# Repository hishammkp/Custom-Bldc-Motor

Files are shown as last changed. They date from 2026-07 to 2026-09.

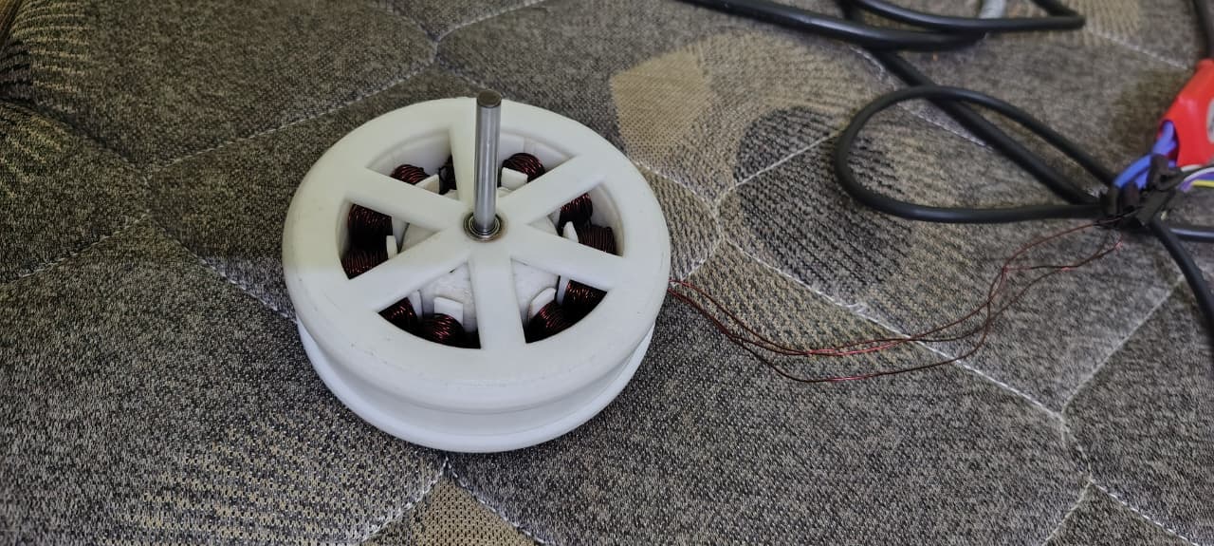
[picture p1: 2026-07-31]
Images/AssembledMotor.jpeg

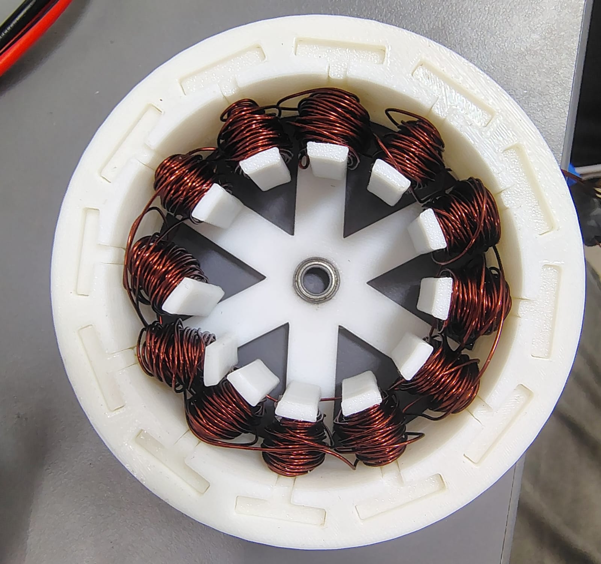
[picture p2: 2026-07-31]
Images/StatorWindings.jpeg

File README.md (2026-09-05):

# Custom BLDC Motor Design

A custom **12-slot, 8-pole Brushless DC (BLDC) motor** designed and developed as part of an electrical engineering coursework project. The project involved the complete engineering workflow, including motor design, CAD modeling, 3D printing, stator winding, assembly, simulation, and experimental validation.

## Overview

The objective of this project was to design and fabricate a functional BLDC motor from scratch rather than using a commercially available motor. The stator, rotor, and supporting components were modeled in Onshape, fabricated using 3D printing, assembled with hand-wound copper windings and permanent magnets, and evaluated through simulation and practical testing.

## Features

* Custom 12-slot, 8-pole inner-rotor BLDC motor
* CAD modeling using Onshape
* 3D-printed stator, rotor, and support components
* Hand-wound stator coils with Star (Y) connection
* Electromagnetic simulation and back-EMF analysis
* Prototype fabrication, assembly, and testing
* Iterative design improvements based on experimental observations

## Design Specifications

| Parameter | Value |
| --- | --- |
| Motor Type | Brushless DC (BLDC) |
| Topology | Inner Rotor |
| Slots | 12 |
| Poles | 8 |
| Winding Connection | Star (Y) |
| Wire Diameter | 0.5 mm Enamelled Copper |
| Winding Factor | 0.866 |

## Software Used

* Onshape
* Altair FluxMotor 2026
* Bambu Studio

## Challenges & Improvements

During fabrication and testing, manufacturing tolerances led to stator slot breakage, low rotor infill caused instability, and magnets detached at higher speeds. These issues were mitigated through stator modifications, improved magnet retention, and iterative design refinements, resulting in a more robust and reliable prototype.

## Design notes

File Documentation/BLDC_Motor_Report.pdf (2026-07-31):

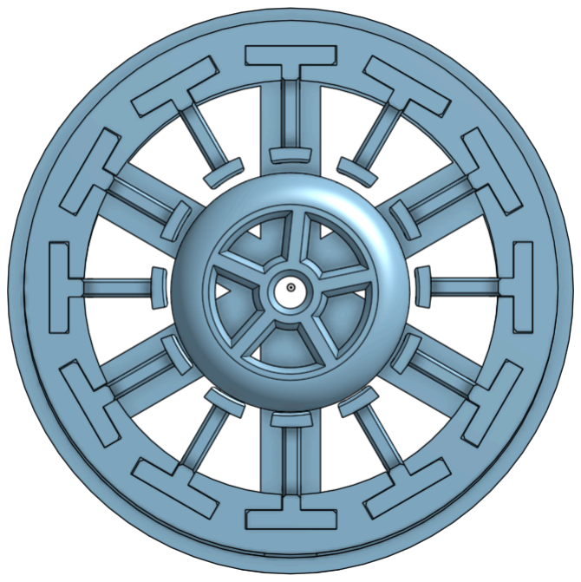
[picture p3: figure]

# BRUSHLESS DC MOTOR

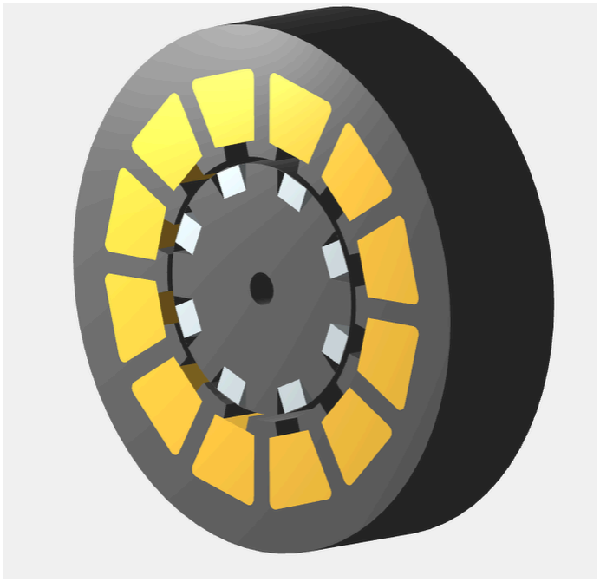
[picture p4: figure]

A Brushless DC (BLDC) motor operates through the interaction of a rotating magnetic field in the stator and permanent magnets in the rotor, generating torque based on the Lorentz Force. Unlike brushed motors, it uses electronic commutation, making it more efficient, reliable, and low maintenance.
DC supply is converted into a 3-phase supply using an ESC (Electronic Speed Controller)
The 3-phase supply is fed to the stator (Y-connected 3-phase windings), creating a rotating magnetic field (RMF)
The rotor contains strong permanent neodymium magnets, whose magnetic field aligns with the RMF, resulting in torque generation

# Understanding How a BLDC Motor Works

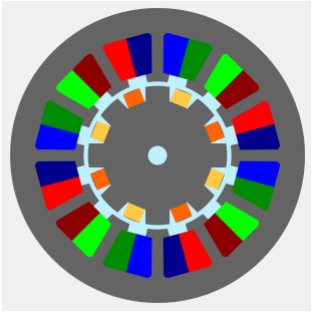
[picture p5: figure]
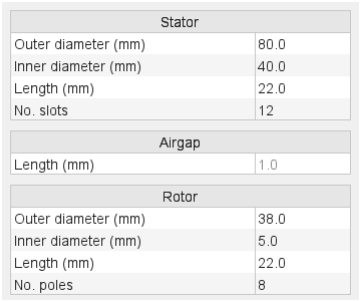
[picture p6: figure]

16 Slot 8pole Inner Rotor | Stator and Rotor Parameters

# Topology of motor

# Stator Winding

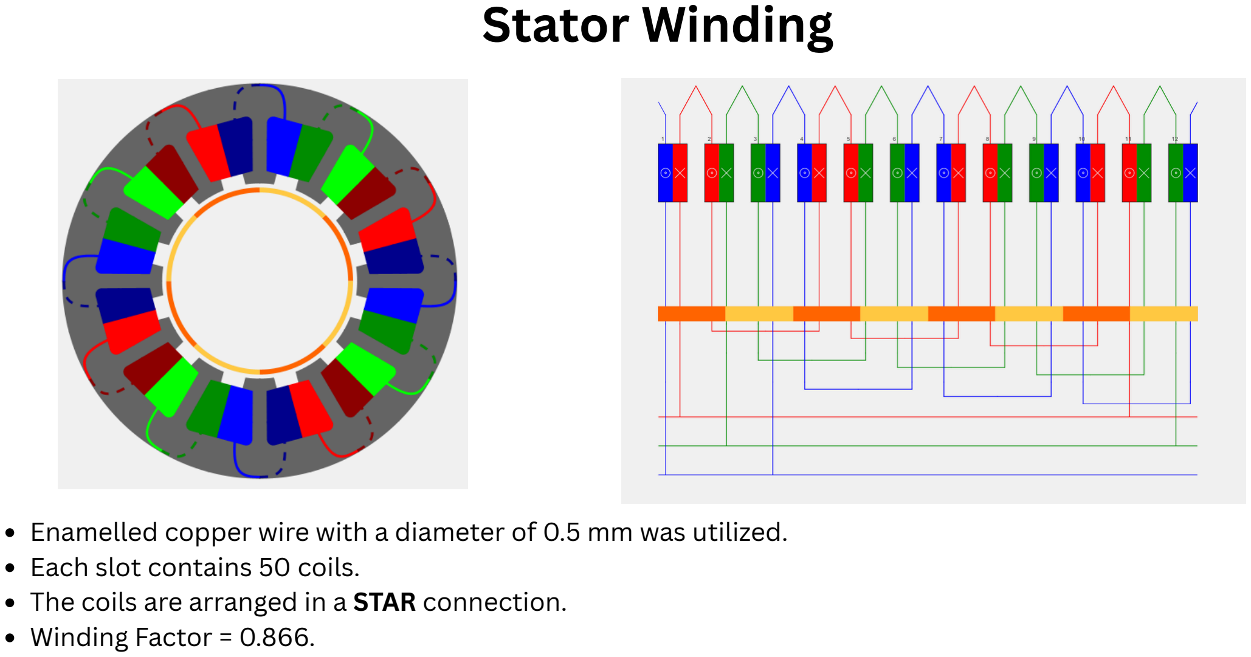
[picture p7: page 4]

Enamelled copper wire with a diameter of 0.5 mm was utilized. Each slot contains 50 coils.
The coils are arranged in a STAR connection.
Winding Factor = 0.866.

# CAD Design

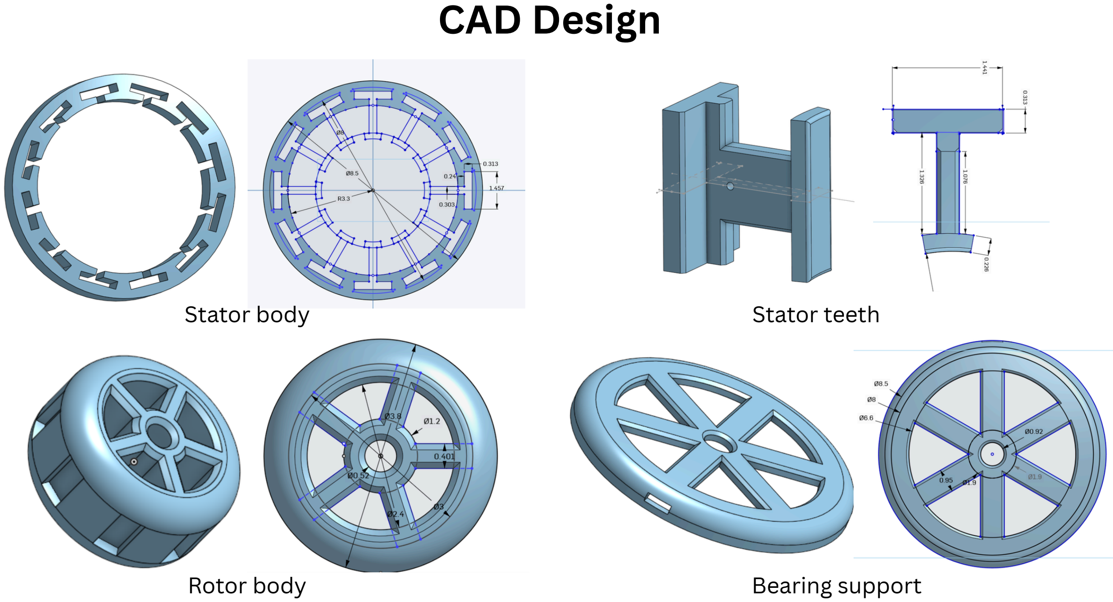
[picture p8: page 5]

Stator body | Stator teeth

Bearing support

Rotor body

# Assembly

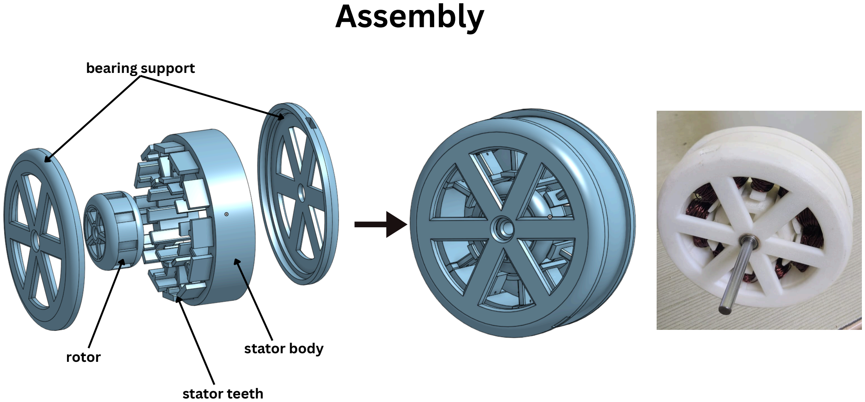
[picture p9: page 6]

bearing support

stator body

stator teeth

rotor

# Simulation

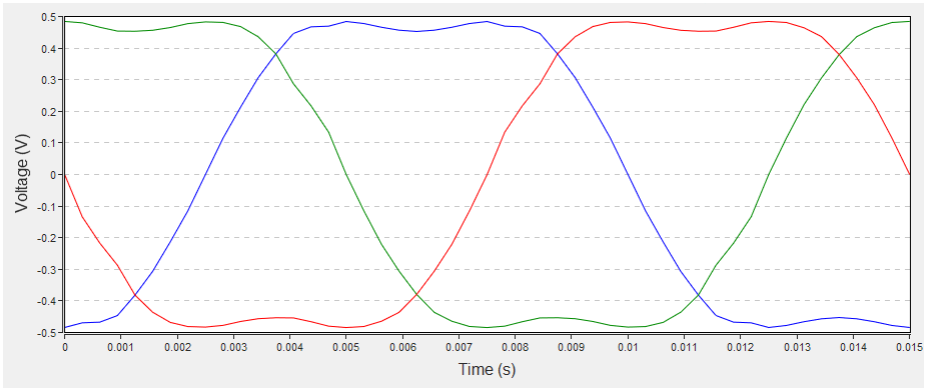
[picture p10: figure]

Phase voltage versus time - Open circuit Test speed = 1000RPM

BLDC motors have a characteristic trapezoidal back EMF waveform, which occurs because the stator winding interacts with rectangular permanent magnets on the rotor

Flat region (under North pole)
Sudden drop (at the edge of the magnet) Flat region (under South pole)
Sudden rise (at the edge of the magnet)

This results in a quasi-trapezoidal back EMF waveform, which is typical for BLDC motors.
The small ripples observed on the waveform are due to harmonics that combine (via Fourier series) to form the final trapezoidal shape.

# Back emf test

# Flux Density Due to Rotor Magnets

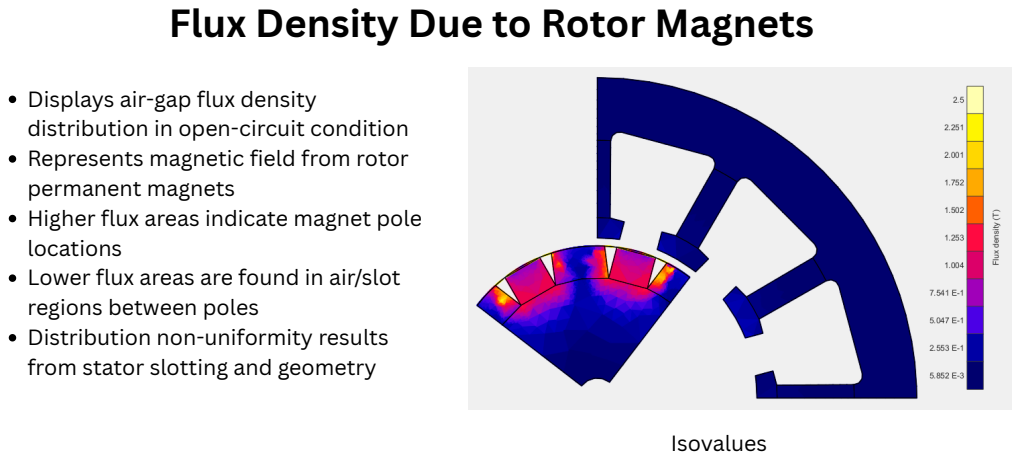
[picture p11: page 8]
Isovalues

Displays air-gap flux density
distribution in open-circuit condition
Represents magnetic field from rotor
permanent magnets
Higher flux areas indicate magnet pole
locations
Lower flux areas are found in air/slot
regions between poles
Distribution non-uniformity results
from stator slotting and geometry

Differences in CAD model and particle 3D model tolerances led to repeated breakage of stator slots
Low 3D fill (15%) resulted in a lighter rotor, which caused increased instability and wobbling
At high speeds, rotor magnets dislodged, resulting in damage to the stator Selection of appropriate vendor for components
SOLUTION
Sanded the stator's teeth to create additional space for the rotor and mitigate vibrations
Secured the magnets using superglue and added tape to minimize the risk of them coming loose

# Challenges faced and solutions implemented

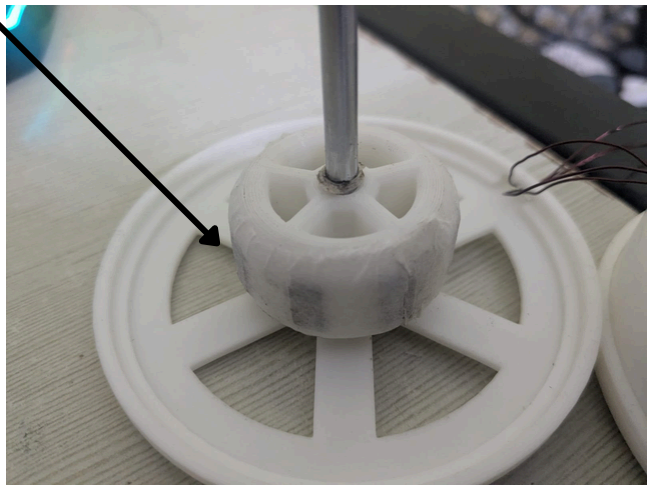
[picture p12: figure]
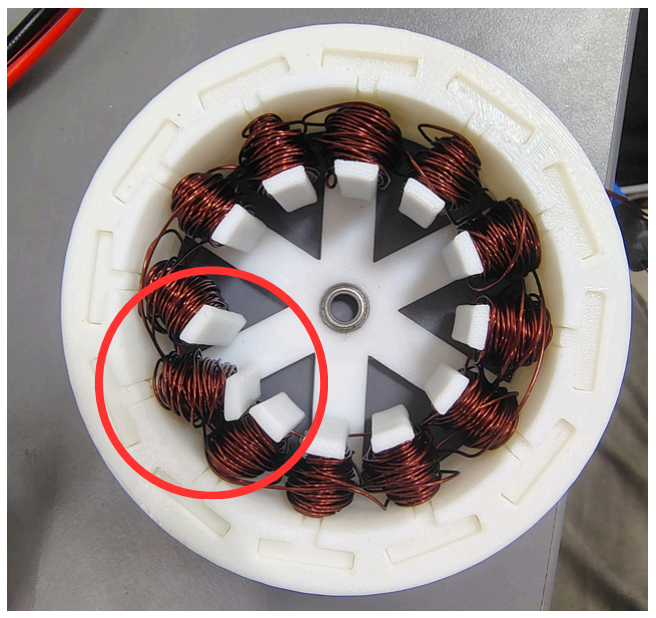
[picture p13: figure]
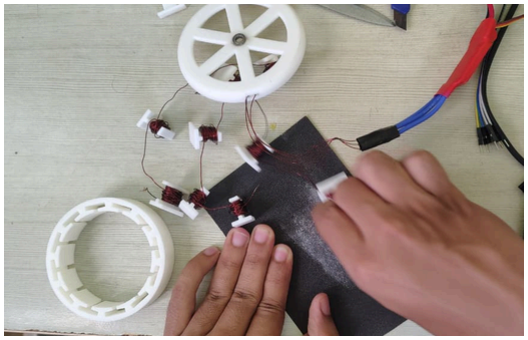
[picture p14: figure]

Onshape
Altair Flux Motor 2026
Bambu Studio

# Softwares used

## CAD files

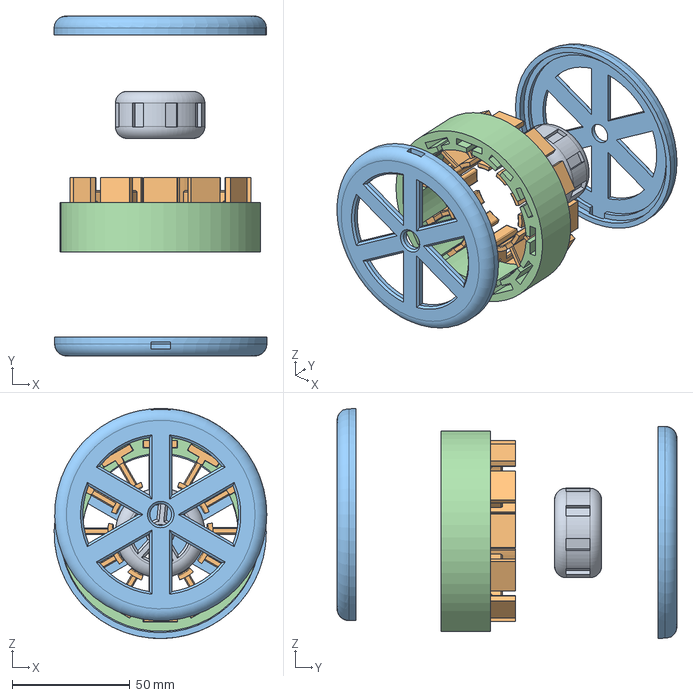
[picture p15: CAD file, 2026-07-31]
CAD/STEP/Assembly.step
90.2 x 144.2 x 97.6 mm

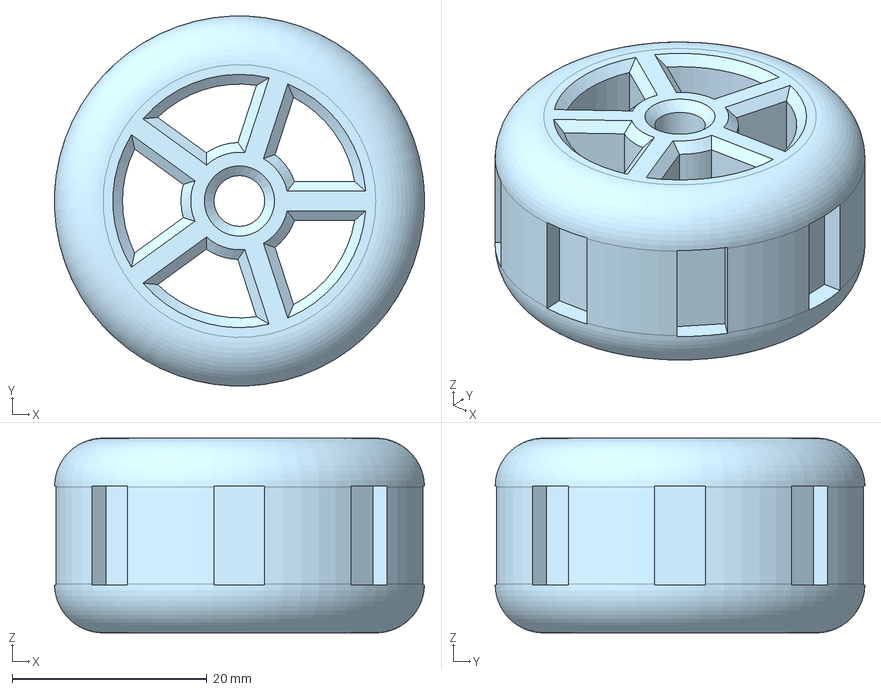
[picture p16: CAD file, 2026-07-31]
CAD/STEP/Rotor.step
38.0 x 38.0 x 20.0 mm

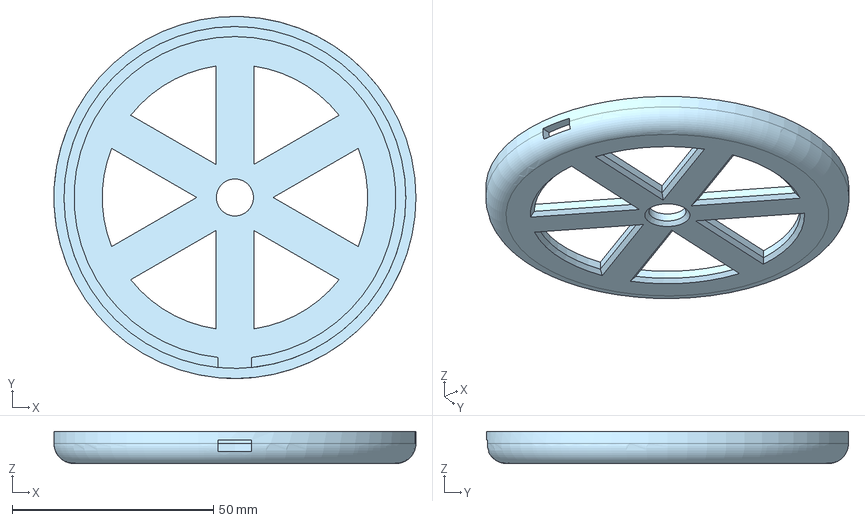
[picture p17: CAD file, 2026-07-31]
CAD/STEP/StatorFrontCover.step
90.0 x 90.0 x 8.00 mm

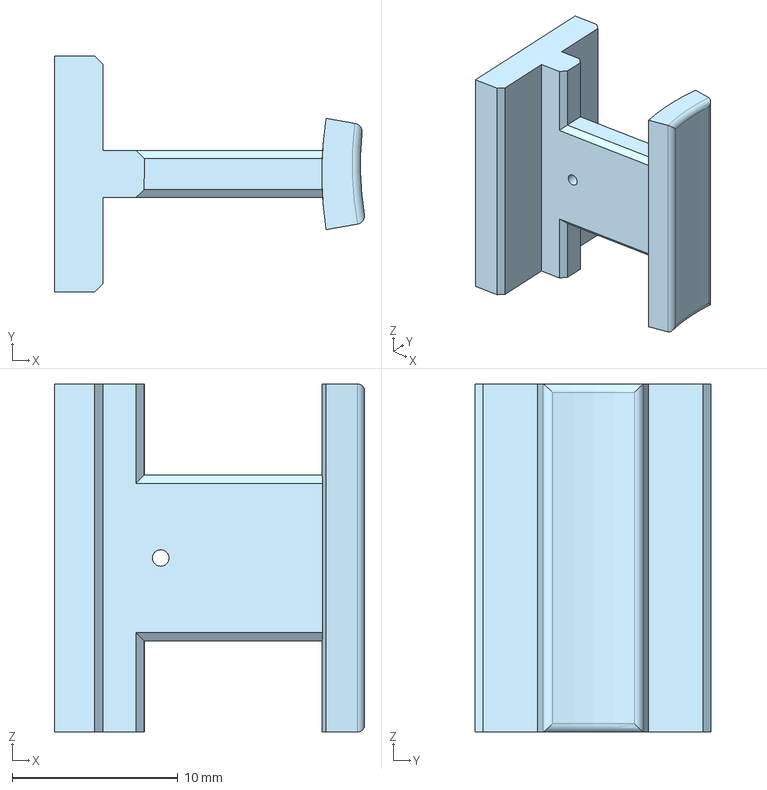
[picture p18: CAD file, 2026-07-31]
CAD/STEP/Slot.step
18.7 x 14.3 x 21.0 mm

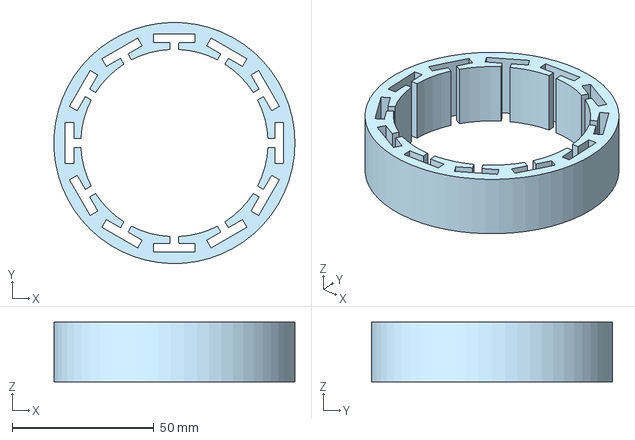
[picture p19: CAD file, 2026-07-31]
CAD/STEP/Stator.step
84.9 x 85.0 x 21.0 mm

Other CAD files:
CAD/STL/Assembly.stl
CAD/STL/Rotor.stl
CAD/STL/Slot.stl
CAD/STL/Stator.stl
CAD/STL/StatorFrontCover.stl

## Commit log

2026-07-31 Initial commit: add custom BLDC motor design files and documentation
    [Assembly.step, Assembly.stl, Rotor.step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]
2026-09-05 Update motor design specifications from 16 to 12 slots
